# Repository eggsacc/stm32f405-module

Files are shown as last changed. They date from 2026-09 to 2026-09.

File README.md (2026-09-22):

<div align="center">

# STM32F405 Dev Module + BLDC hat





### MCU Dev
STM32F405RGT6 MCU dev module with commonly used peripherals broken out for easy access, and a dedicated CAN transceiver. Also includes 2 user programmable buttons and mini OLED display.

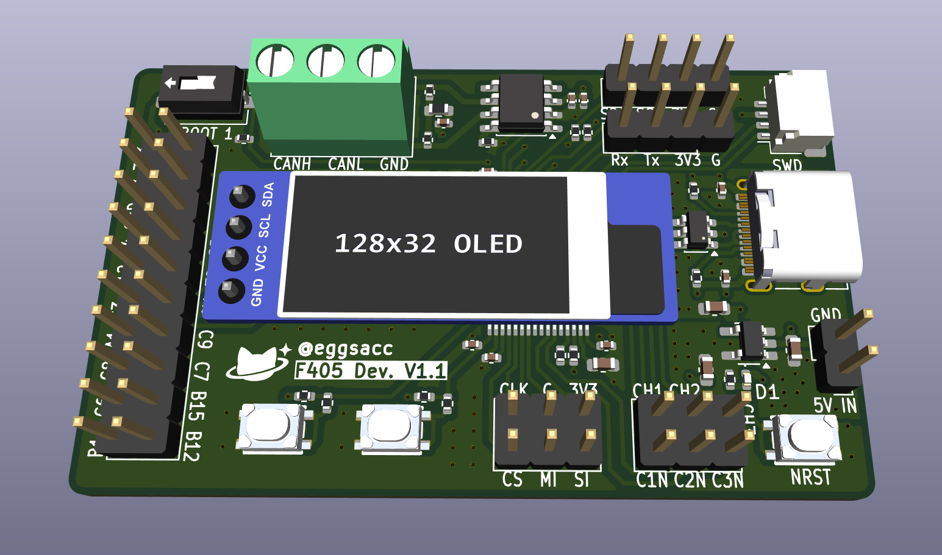
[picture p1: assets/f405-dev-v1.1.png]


### BLDC Dev
BLDC hat based on the DRV8316C integrated driver. 6-PWM mode, 5-35V input, 5A continuous and 3-phase low-side current sensing. Suitable for FOC algorithm developement and testing for low current gimbal motors.

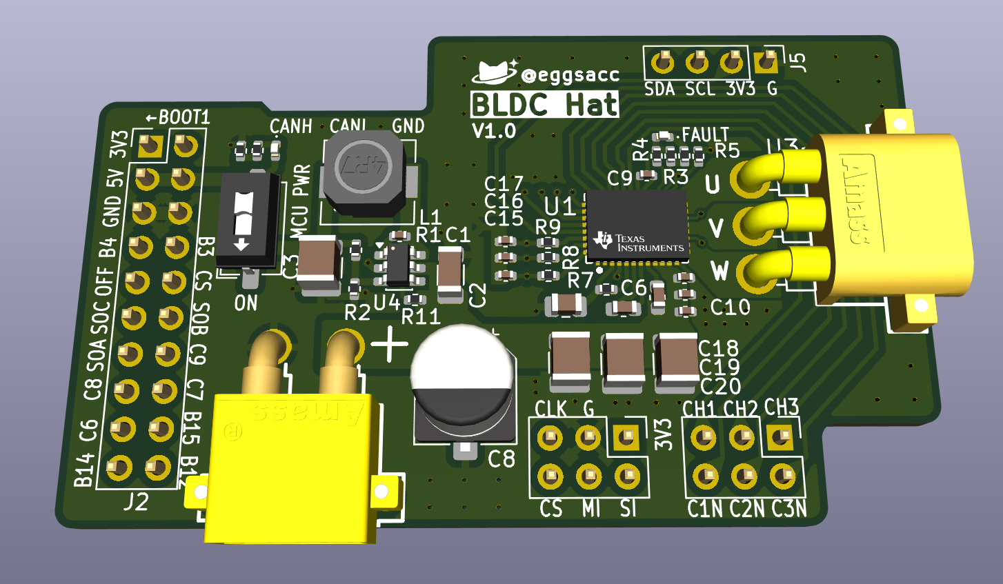
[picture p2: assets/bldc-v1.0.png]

</div>

---

## MCU Pinout

<div align="center">
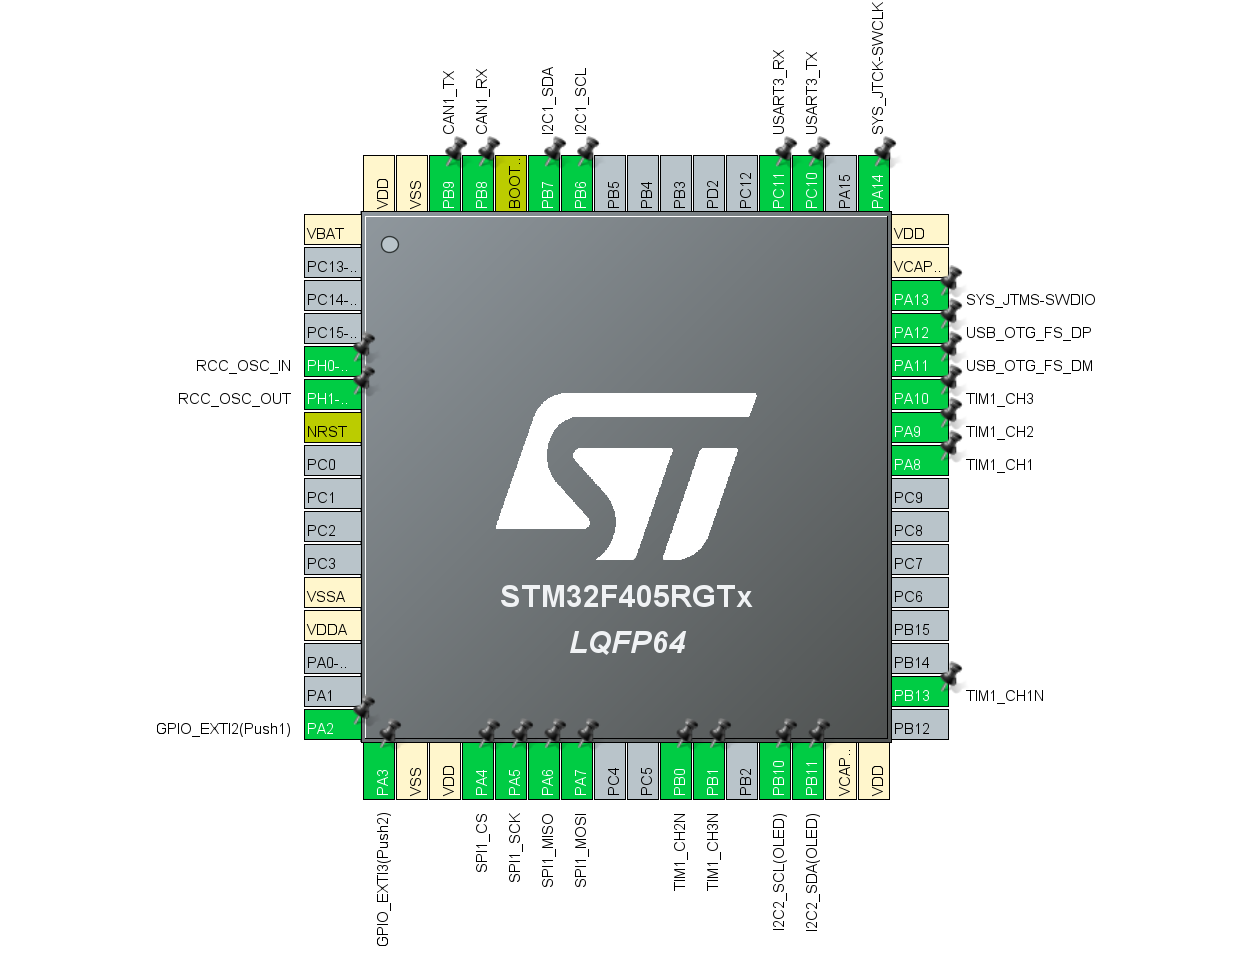
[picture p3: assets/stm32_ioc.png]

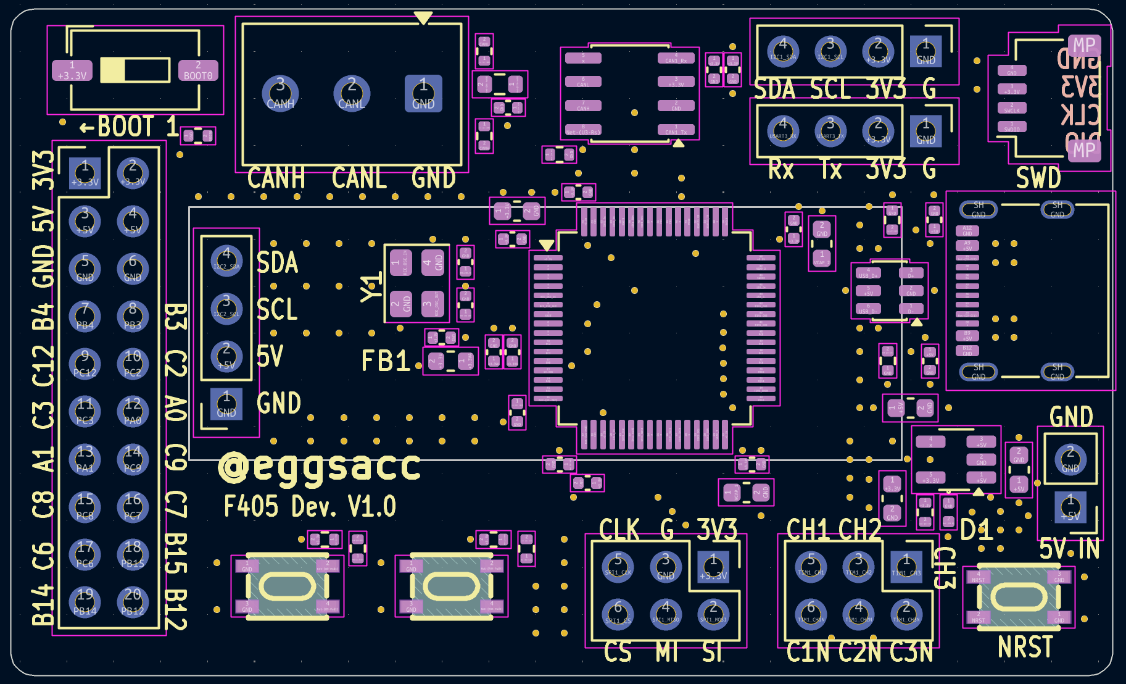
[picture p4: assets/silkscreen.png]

</div>

---

| Breakout / feature | Peripheral | Pin mapping |
|---|---|---|
| **UART header** | `USART3` | TX &rarr; `PC10`<br>RX &rarr; `PC11` |
| **SPI header** | `SPI1` | CS &rarr; `PA4`<br>SCK &rarr; `PA5`<br>MISO &rarr; `PA6`<br>MOSI &rarr; `PA7` |
| **I2C header** | `I2C1` | SCL &rarr; `PB6`<br>SDA &rarr; `PB7` |
| **CAN screw terminal** | `CAN1` (SN65HVD230) | TX &rarr; `PB9`<br>RX &rarr; `PB8` |
| **USB-C** | `USB_OTG_FS` | D&minus; &rarr; `PA11`<br>D+ &rarr; `PA12` |
| **SWD header** | `SYS` | SWDIO &rarr; `PA13`<br>SWCLK &rarr; `PA14` |
| **3-phase PWM header** | `TIM1` | <table><tbody><tr><td align="right">CH1 &rarr;</td><td><code>PA8</code></td><td align="right">&emsp;C1N &rarr;</td><td><code>PB13</code></td></tr><tr><td align="right">CH2 &rarr;</td><td><code>PA9</code></td><td align="right">&emsp;C2N &rarr;</td><td><code>PB0</code></td></tr><tr><td align="right">CH3 &rarr;</td><td><code>PA10</code></td><td align="right">&emsp;C3N &rarr;</td><td><code>PB1</code></td></tr></tbody></table> |
| **OLED** (on-board) | `I2C2` | SCL &rarr; `PB10`<br>SDA &rarr; `PB11` |
| **Utility buttons** (on-board) | `GPIO` / `EXTI` | L button &rarr; `PA2`<br>R button &rarr; `PA3` |
| **Crystal** (25MHz) | `RCC` HSE | OSC_IN &rarr; `PH0`<br>OSC_OUT &rarr; `PH1` |
| **GPIO header** (2&times;10) | free GPIO | <table><tbody><tr><td align="right">1 &rarr;</td><td><code>3.3V</code></td><td align="right">&emsp;2 &rarr;</td><td><code>3.3V</code></td></tr><tr><td align="right">3 &rarr;</td><td><code>5V</code></td><td align="right">&emsp;4 &rarr;</td><td><code>5V</code></td></tr><tr><td align="right">5 &rarr;</td><td><code>GND</code></td><td align="right">&emsp;6 &rarr;</td><td><code>GND</code></td></tr><tr><td align="right">7 &rarr;</td><td><code>PB4</code></td><td align="right">&emsp;8 &rarr;</td><td><code>PB3</code></td></tr><tr><td align="right">9 &rarr;</td><td><code>PC12</code></td><td align="right">&emsp;10 &rarr;</td><td><code>PC2</code></td></tr><tr><td align="right">11 &rarr;</td><td><code>PC3</code></td><td align="right">&emsp;12 &rarr;</td><td><code>PA0</code></td></tr><tr><td align="right">13 &rarr;</td><td><code>PA1</code></td><td align="right">&emsp;14 &rarr;</td><td><code>PC9</code></td></tr><tr><td align="right">15 &rarr;</td><td><code>PC8</code></td><td align="right">&emsp;16 &rarr;</td><td><code>PC7</code></td></tr><tr><td align="right">17 &rarr;</td><td><code>PC6</code></td><td align="right">&emsp;18 &rarr;</td><td><code>PB15</code></td></tr><tr><td align="right">19 &rarr;</td><td><code>PB14</code></td><td align="right">&emsp;20 &rarr;</td><td><code>PB12</code></td></tr></tbody></table> |

> Buttons are active-low to GND (3V3 pull-up).

---

## Power

>[!warning]Shared +5V rail
>5V rails are shared; do not connect USB and external power simultaneously!

- **USB-C**, 2-pin **`5V IN`** header, or `5V` on 2x10 breakout.
- AP2112K-3.3 LDO provides the 3.3 V rail (600 mA max).

---

## BLDC Hat hardware
<div align="center">
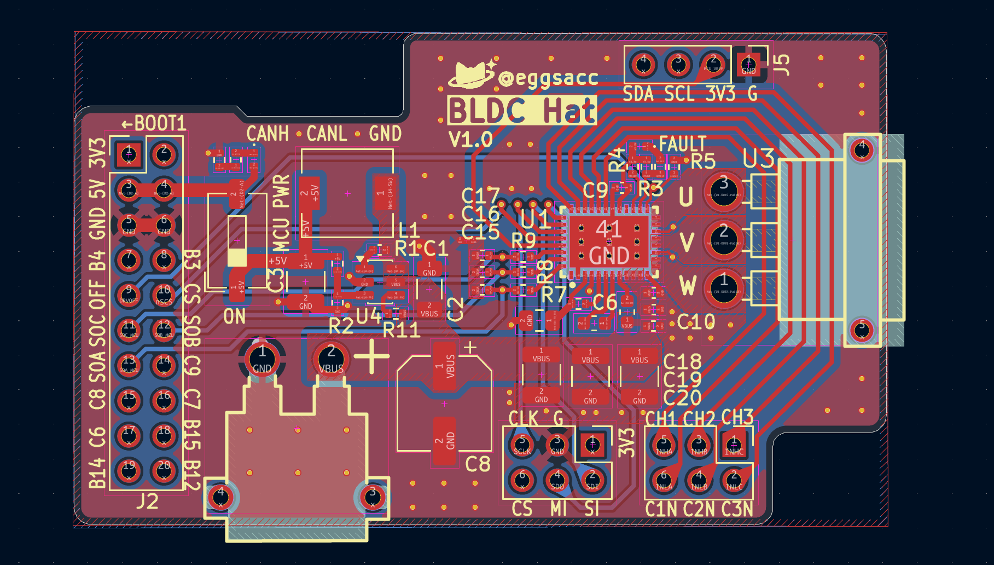
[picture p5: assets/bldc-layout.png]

</div>

---
<div align="center">
Designed by <b>@eggsacc</b> · F405 Dev. V1.1<br>
Updated 22/09/2026
</div>

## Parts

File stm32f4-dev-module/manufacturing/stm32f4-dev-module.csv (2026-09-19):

Reference | Qty | Value | Footprint | Purhased | Qty | Link
C1,C2,C3,C4,C5,C13,C16,C22,C23,C24 | 10 | 100n | Capacitor_SMD:C_0402_1005Metric | TRUE | 100 | 0402??????? 22pF33pF47pF100pF2.2nF4.7nF100nF1uF10uF-???
C6 | 1 | 10u | Capacitor_SMD:C_0603_1608Metric | TRUE | 100 | 0603??????? 22pF33pF47pF100pF2.2nF4.7nF100nF1uF10uF-???
C7,C21 | 2 | 10n | Capacitor_SMD:C_0402_1005Metric | TRUE | 100 | 0402??????? 22pF33pF47pF100pF2.2nF4.7nF100nF1uF10uF-???
C8,C9,C17 | 3 | 1u | Capacitor_SMD:C_0402_1005Metric | TRUE | 100 | 0402??????? 22pF33pF47pF100pF2.2nF4.7nF100nF1uF10uF-???
C10,C11 | 2 | 14p | Capacitor_SMD:C_0402_1005Metric | TRUE | 100 | 0402??????? 22pF33pF47pF100pF2.2nF4.7nF100nF1uF10uF-???
C14,C15 | 2 | 1u | Capacitor_SMD:C_0603_1608Metric | TRUE | 100 | 0603??????? 22pF33pF47pF100pF2.2nF4.7nF100nF1uF10uF-???
C18,C19 | 2 | 2u2 | Capacitor_SMD:C_0603_1608Metric | TRUE | 100 | 0603??????? 22pF33pF47pF100pF2.2nF4.7nF100nF1uF10uF-???
C20 | 1 | 4u7 | Capacitor_SMD:C_0603_1608Metric | TRUE | 100 | 0603??????? 22pF33pF47pF100pF2.2nF4.7nF100nF1uF10uF-???
D1 | 1 | GREEN | LED_SMD:LED_0402_1005Metric | TRUE | 10 | ??LED 0402 0603 0805 1206??????? ?????????-tmall.com??
FB1 | 1 | 120R | Inductor_SMD:L_0603_1608Metric | TRUE | 100 | 0603?????????30R60R100R120R150R220R300R600R1K2K2.5K-???
J1 | 1 | SW | Connector_JST:JST_SH_SM04B-SRSS-TB_1x04-1MP_P1.00mm_Horizontal | TRUE | 10 | ???SH1.0??JSTSH ???1.0mm????/??/???????-???
J3 | 1 | I2C1 | Connector_PinHeader_2.54mm:PinHeader_1x04_P2.54mm_Vertical | TRUE | 0
J4 | 1 | SPI1 | Connector_PinHeader_2.54mm:PinHeader_2x03_P2.54mm_Vertical | TRUE | 0 | ?/??? ??2.54MM 1*2p/3p/4p/8P/16p/20p?? LCD1602/12864-tmall.com??
J5 | 1 | 5V_IN | Connector_PinHeader_2.54mm:PinHeader_1x02_P2.54mm_Vertical | TRUE | 0
J6 | 1 | OLED | addons:OLED header | TRUE | 0
J7 | 1 | USB_C_Receptacle_USB2.0_16P | Connector_USB:USB_C_Receptacle_G-Switch_GT-USB-7010ASV | TRUE | 0 | USB Type-C 16P?????????????????USB???-???
J8 | 1 | USART3 | Connector_PinHeader_2.54mm:PinHeader_1x04_P2.54mm_Vertical | TRUE | 0
J9 | 1 | PWM | Connector_PinHeader_2.54mm:PinHeader_2x03_P2.54mm_Vertical | TRUE | 0
J10 | 1 | Screw_Terminal_01x03 | TerminalBlock_Phoenix:TerminalBlock_Phoenix_MKDS-1-3-3.81_1x03_P3.81mm_Horizontal | TRUE | 0 | KF128/126????2P???2.54/3.81/5.08MM??5.0?????3P-tmall.com??
J11 | 1 | Conn_02x10_Odd_Even | Connector_PinHeader_2.54mm:PinHeader_2x10_P2.54mm_Vertical | TRUE | 0
R1,R3,R10,R12 | 4 | 10k | Resistor_SMD:R_0402_1005Metric | TRUE | 0 | 0402?????? ??1% 10R1K1.2K2.2K3.3K4.7K5.1K10K100K1M?-???
R2 | 1 | 330 | Resistor_SMD:R_0402_1005Metric | TRUE | 0 | 0402?????? ??1% 10R1K1.2K2.2K3.3K4.7K5.1K10K100K1M?-???
R4,R5 | 2 | 60 | Resistor_SMD:R_0402_1005Metric | TRUE | 0 | 0402?????? ??1% 10R1K1.2K2.2K3.3K4.7K5.1K10K100K1M?-???
R6 | 1 | 0 | Resistor_SMD:R_0603_1608Metric | TRUE | 0 | 0402 0603 0805 1206????1%5% 1R10R100R1K 4.7K10K 47K 100K-???
R7,R8 | 2 | 5k1 | Resistor_SMD:R_0402_1005Metric | TRUE | 0 | 0402?????? ??1% 10R1K1.2K2.2K3.3K4.7K5.1K10K100K1M?-???
R9,R11 | 2 | 100 | Resistor_SMD:R_0402_1005Metric | TRUE | 0 | 0402?????? ??1% 10R1K1.2K2.2K3.3K4.7K5.1K10K100K1M?-???
SW1 | 1 | SW_SPST | Button_Switch_SMD:SW_DIP_SPSTx01_Slide_6.7x4.1mm_W6.73mm_P2.54mm_LowProfile_JPin | TRUE | 10 | ??????/??1/2/3/4/5/6/7/8/9/10/12p??1.27/2.54mm??-???
SW5,SW6 | 2 | BTN_UTIL | addons:SW-SMD_4P-L4.2-W3.4-P2.15-LS5.2 | TRUE | 0 | ????4???2??????????????????????-tmall.com??
SW7 | 1 | BTN | addons:SW-SMD_4P-L4.2-W3.4-P2.15-LS5.2 | TRUE | 40 | ????4???2??????????????????????-tmall.com??
U1 | 1 | STM32F405RGT6 | Package_QFP:LQFP-64_10x10mm_P0.5mm | TRUE | 2 | ???? STM32F405RGT6 STM32F405VGT6 405ZGT6 405OEY6TR VGT7-tmall.com??
U2 | 1 | USBLC6-2SC6 | Package_TO_SOT_SMD:SOT-23-6 | TRUE | 20 | USBLC6-2SC6 USB2.0??ESD????? ???? ??UL26 SOT-23-tmall.com??
U3 | 1 | SN65HVD230 | Package_SO:SOIC-8_3.9x4.9mm_P1.27mm | TRUE | 5 | ???? ?? SN65HVD230DR SOP-8 CAN????? ??-???
U4 | 1 | AP2112K-3.3 | Package_TO_SOT_SMD:SOT-23-5_HandSoldering | TRUE | 10 | AP2112K-3.3TRG1 1.2V 1.8V 2.5V ??G3M LDO????? SOT23-5-???
Y1 | 1 | 25MHz | Crystal:Crystal_SMD_3225-4Pin_3.2x2.5mm | TRUE | 10 | 3225_4P???????? 8/12/13.56/16/20/24/25/26/32/40MHz-???
 |  |  | Request from seller values
 | ??
 | 1 | 100nF, 16V, X7R | 0402
 | 2 | 10nF, 50V, X7R | 0402
 | 3 | 1uF, 25V, X5R, 10% | 0402
 | 4 | 13pF, 50V, C0G | 0402
 | 5 | 1uF, 16V, X7R, 10% | 0603
 | 6 | 2.2uF, 16V, X7R, 10% | 0603
 | 7 | 4.7uF, 16V, X5R, 10% | 0603
 | 8 | 10uF, 10V, X5R, 10% | 0603
 | ??
 | 1 | 10k | 0402
 | 2 | 330 | 0402
 | 3 | 60 | 0402
 | 4 | 5.1K | 0402
 | 5 | 100 | 0403
 | 6 | 0 | 0603

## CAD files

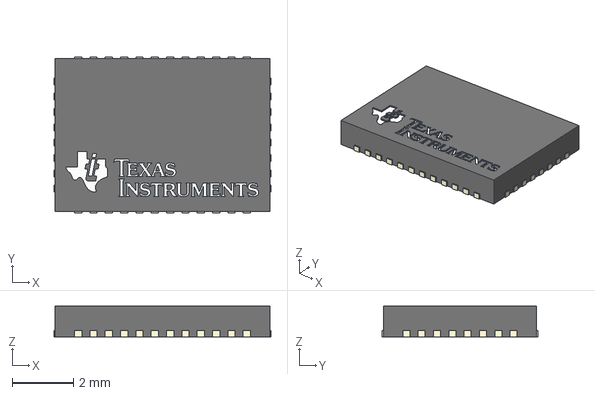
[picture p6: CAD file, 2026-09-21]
bldc-hat/3d-models/VQFN40p-7x5-TI.step
7.08 x 5.09 x 1.00 mm

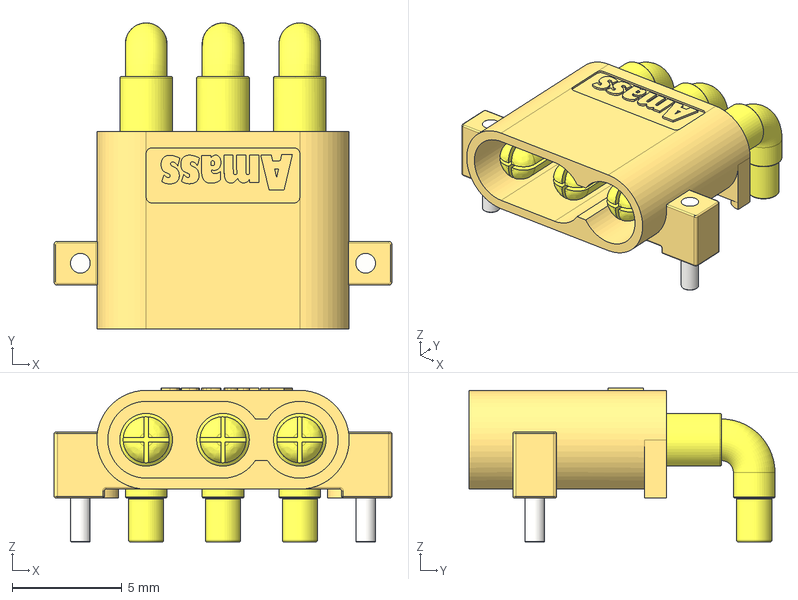
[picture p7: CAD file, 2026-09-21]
bldc-hat/3d-models/MR30PW-M v2.step
15.4 x 13.9 x 7.00 mm
PCB Pins
Pin 2 x 3

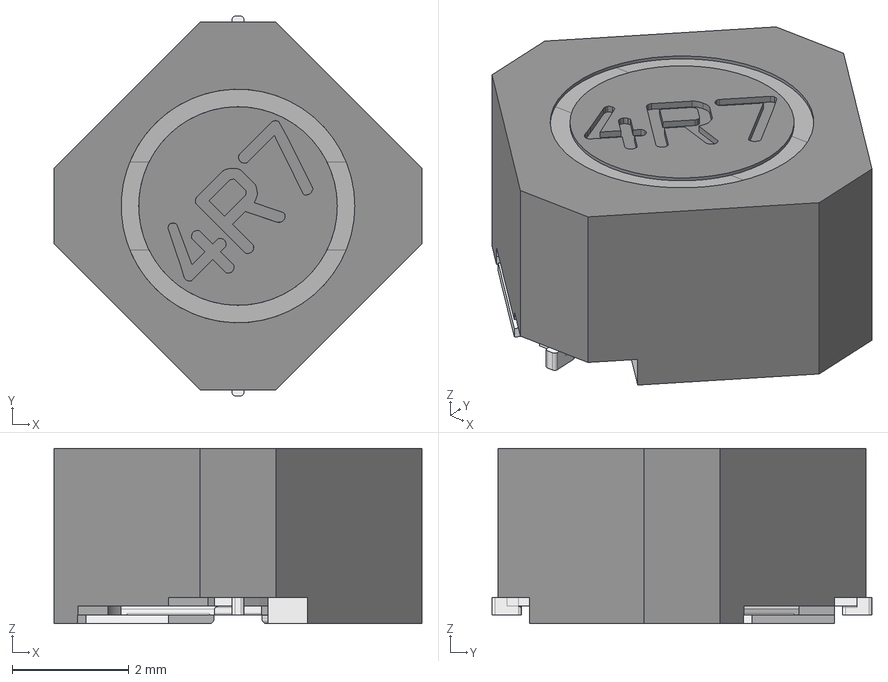
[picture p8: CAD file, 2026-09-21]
bldc-hat/3d-models/Inductor_63.step
6.30 x 6.50 x 3.00 mm
Protection
Inner_Pins
Inductor_Core
Pins
Inductor_Case

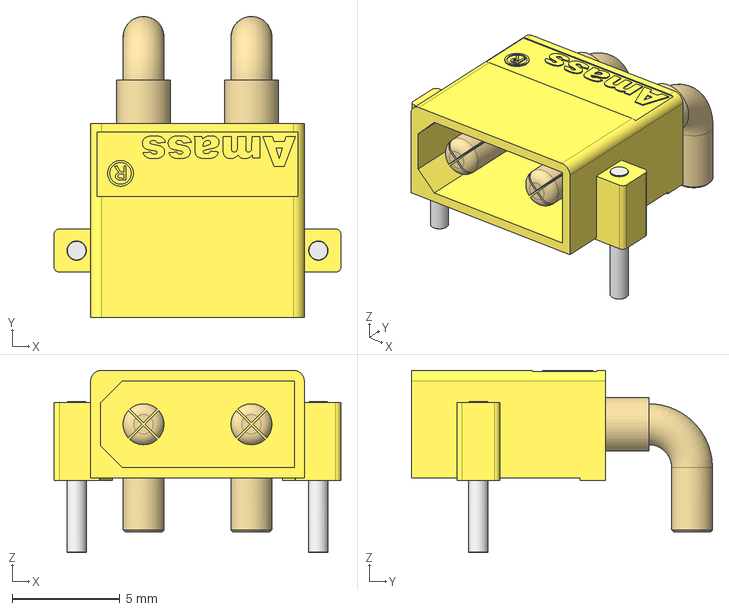
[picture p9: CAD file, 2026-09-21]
bldc-hat/3d-models/Amass_XT30PW-M_pcb solder.stp
13.3 x 13.9 x 8.45 mm

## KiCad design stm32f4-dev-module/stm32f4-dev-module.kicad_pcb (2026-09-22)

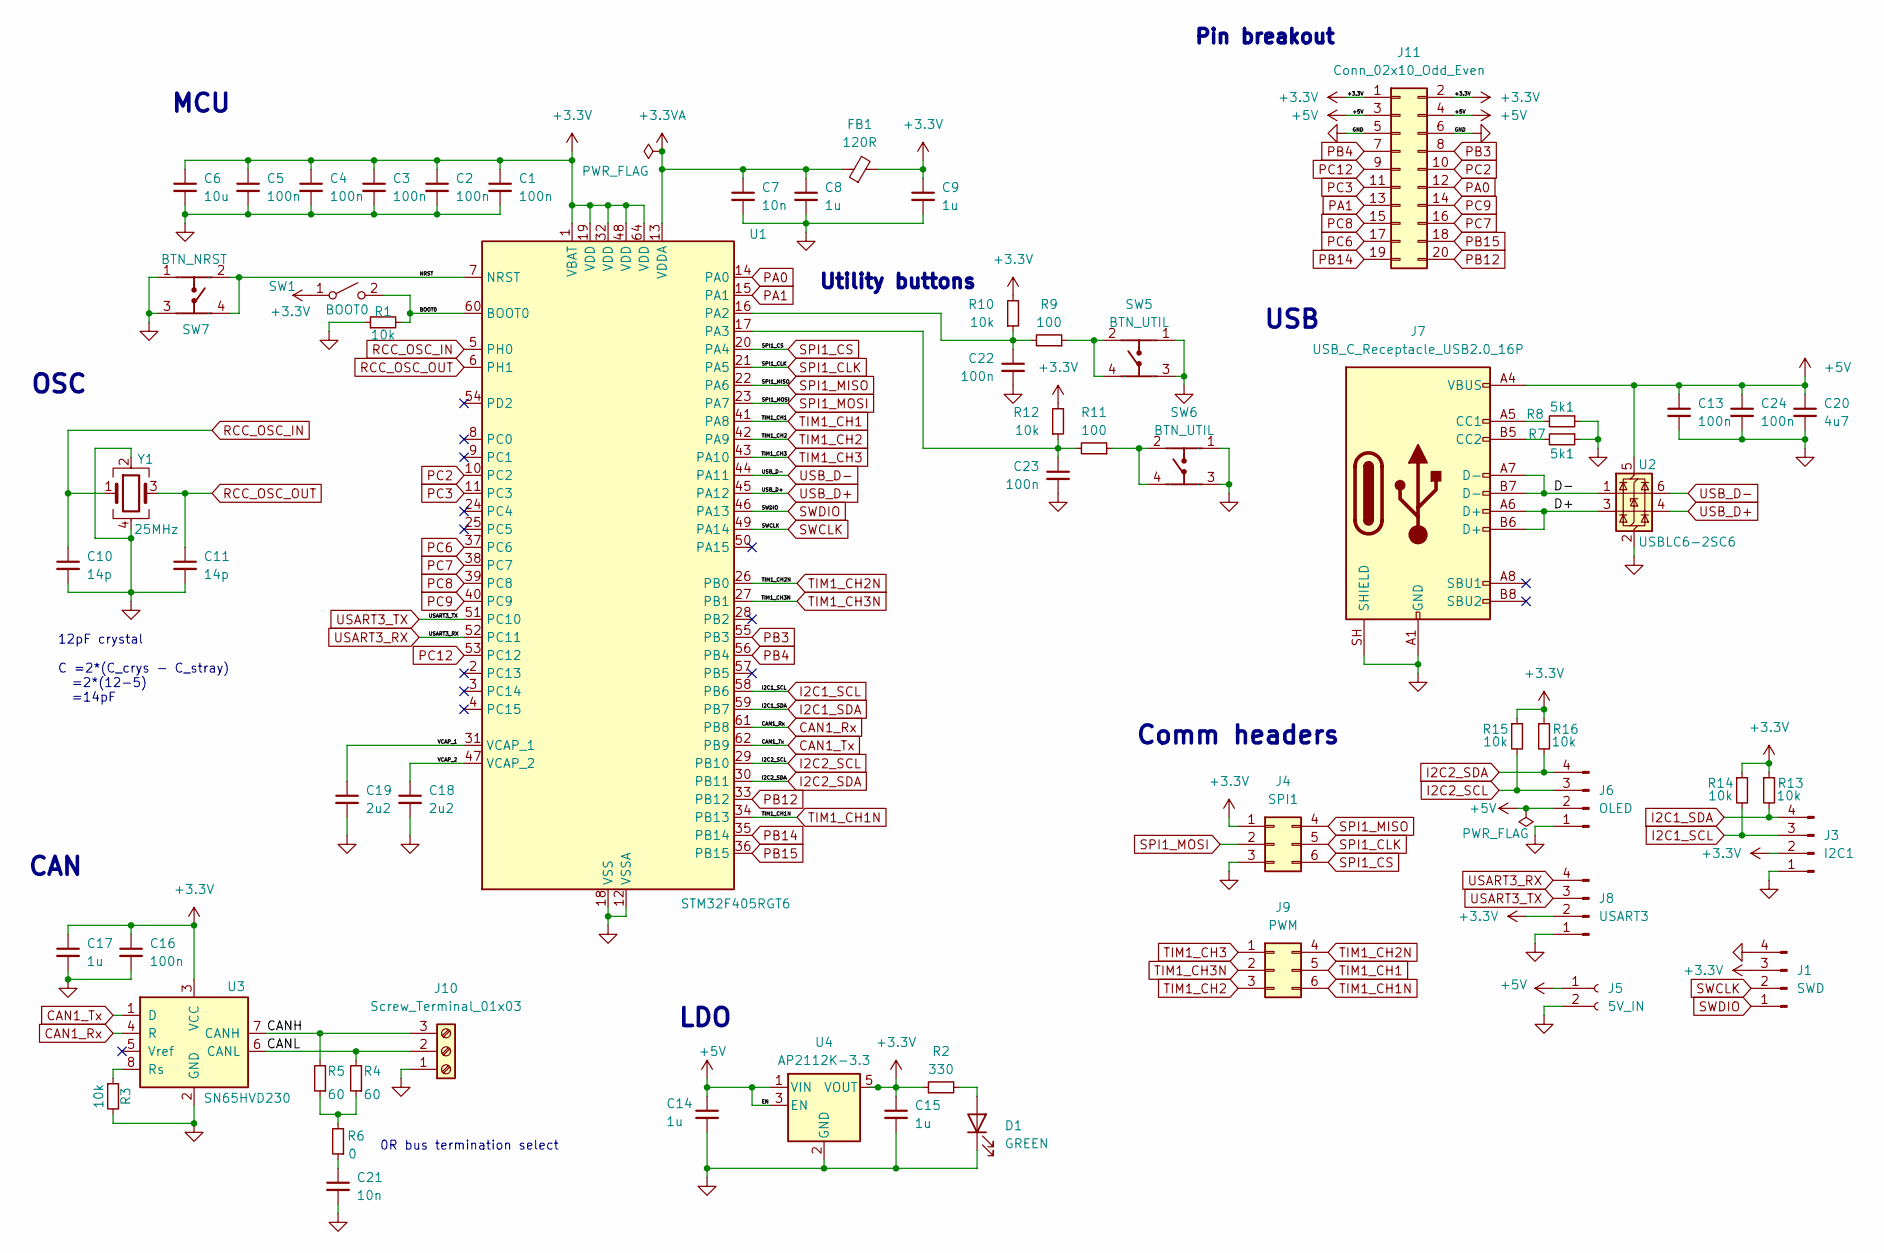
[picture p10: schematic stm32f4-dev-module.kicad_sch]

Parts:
C1, C2, C3, C4, C5, C13, C16, C22, C23, C24: 100n; C_0402_1005Metric
C6: 10u; C_0603_1608Metric
C7, C21: 10n; C_0402_1005Metric
C8, C9, C17: 1u; C_0402_1005Metric
C10, C11: 14p; C_0402_1005Metric
C14, C15: 1u; C_0603_1608Metric
C18, C19: 2u2; C_0603_1608Metric
C20: 4u7; C_0603_1608Metric
D1: GREEN; LED_0402_1005Metric
FB1: 120R; L_0603_1608Metric
J1: SWD; JST_SH_SM04B-SRSS-TB_1x04-1MP_P1.00mm_Horizontal
J3: I2C1; PinHeader_1x04_P2.54mm_Vertical
J4: SPI1; PinHeader_2x03_P2.54mm_Vertical
J5: 5V_IN; PinHeader_1x02_P2.54mm_Vertical
J6: OLED; OLED header
J7: USB_C_Receptacle_USB2.0_16P; USB_C_Receptacle_G-Switch_GT-USB-7010ASV
J8: USART3; PinHeader_1x04_P2.54mm_Vertical
J9: PWM; PinHeader_2x03_P2.54mm_Vertical
J10: Screw_Terminal_01x03; TerminalBlock_Phoenix_MKDS-1-3-3.81_1x03_P3.81mm_Horizontal
J11: Conn_02x10_Odd_Even; PinHeader_2x10_P2.54mm_Vertical
R1, R3, R10, R12, R13, R14, R15, R16: 10k; R_0402_1005Metric
R2: 330; R_0402_1005Metric
R4, R5: 60; R_0402_1005Metric
R6: 0; R_0603_1608Metric
R7, R8: 5k1; R_0402_1005Metric
R9, R11: 100; R_0402_1005Metric
SW1: BOOT0; SW_DIP_SPSTx01_Slide_6.7x4.1mm_W6.73mm_P2.54mm_LowProfile_J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
SW5, SW6: BTN_UTIL; SW-SMD_4P-L4.2-W3.4-P2.15-LS5.2; Manufacturer Part HX 3x4x2.5-PA-4N push button switch
SW7: BTN_NRST; SW-SMD_4P-L4.2-W3.4-P2.15-LS5.2; Manufacturer Part HX 3x4x2.5-PA-4N push button switch
U1: STM32F405RGT6; LQFP-64_10x10mm_P0.5mm
U2: USBLC6-2SC6; SOT-23-6
U3: SN65HVD230; SOIC-8_3.9x4.9mm_P1.27mm
U4: AP2112K-3.3; SOT-23-5_HandSoldering
Y1: 25MHz; Crystal_SMD_3225-4Pin_3.2x2.5mm

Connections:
+3.3V: C1.1, C2.1, C3.1, C4.1, C5.1, C6.1, C9.1, C15.1, C16.1, C17.1, FB1.2, J1.3, J3.2, J4.1, J8.2, J11.1, J11.2, R2.1, R10.2, R12.2, R13.1, R14.1, R15.1, R16.1, SW1.1 (A), U1.1 (VBAT), U1.19 (VDD), U1.32 (VDD), U1.48 (VDD), U1.64 (VDD), U3.3 (VCC), U4.5 (VOUT)
+3.3VA: C7.1, C8.1, FB1.1, U1.13 (VDDA)
+5V: C13.1, C14.1, C20.1, C24.1, J5.1, J6.2, J7.A4 (VBUS), J7.A9 (VBUS), J7.B4 (VBUS), J7.B9 (VBUS), J11.3, J11.4, U2.5 (VBUS), U4.1 (VIN), U4.3 (EN)
/BOOT0: R1.2, SW1.2 (B), U1.60 (BOOT0)
/CANH: J10.3, R5.2, U3.7 (CANH)
/CANL: J10.2, R4.2, U3.6 (CANL)
/D+: J7.A6 (D+), J7.B6 (D+), U2.3 (I/O2)
/D-: J7.A7 (D-), J7.B7 (D-), U2.1 (I/O1)
/NRST: SW7.2, SW7.4, U1.7 (NRST)
/VCAP_1: C19.1, U1.31 (VCAP_1)
/VCAP_2: C18.1, U1.47 (VCAP_2)
CAN1_Rx: U1.61 (PB8), U3.4 (R)
CAN1_Tx: U1.62 (PB9), U3.1 (D)
GND: C1.2, C2.2, C3.2, C4.2, C5.2, C6.2, C7.2, C8.2, C9.2, C10.2, C11.2, C13.2, C14.2, C15.2, C16.2, C17.2, C18.2, C19.2, C20.2, C21.2, C22.2, C23.2, C24.2, D1.1 (K), J1.4, J3.1, J4.3, J5.2, J6.1, J7.A1 (GND), J7.A12 (GND), J7.B1 (GND), J7.B12 (GND), J7.SH (SHIELD), J8.1, J10.1, J11.5, J11.6, R1.1, R3.2, R7.1, R8.1, SW5.1, SW5.3, SW6.1, SW6.3, SW7.1, SW7.3, U1.12 (VSSA), U1.18 (VSS), U1.63 (VSS), U2.2 (GND), U3.2 (GND), U4.2 (GND), Y1.2, Y1.4
I2C1_SCL: J3.3, R14.2, U1.58 (PB6)
I2C1_SDA: J3.4, R13.2, U1.59 (PB7)
I2C2_SCL: J6.3, R15.2, U1.29 (PB10)
I2C2_SDA: J6.4, R16.2, U1.30 (PB11)
unnamed: C21.1, R6.1
unnamed: D1.2 (A), R2.2
unnamed: J7.A5 (CC1), R8.2
unnamed: J7.B5 (CC2), R7.2
unnamed: R4.1, R5.1, R6.2
unnamed: R9.1, SW5.2, SW5.4
unnamed: R11.1, SW6.2, SW6.4
unnamed: C22.1, R9.2, R10.1, U1.16 (PA2)
unnamed: C23.1, R11.2, R12.1, U1.17 (PA3)
unnamed: R3.1, U3.8 (Rs)
PA0: J11.12, U1.14 (PA0)
PA1: J11.13, U1.15 (PA1)
PB3: J11.8, U1.55 (PB3)
PB4: J11.7, U1.56 (PB4)
PB12: J11.20, U1.33 (PB12)
PB14: J11.19, U1.35 (PB14)
PB15: J11.18, U1.36 (PB15)
PC2: J11.10, U1.10 (PC2)
PC3: J11.11, U1.11 (PC3)
PC6: J11.17, U1.37 (PC6)
PC7: J11.16, U1.38 (PC7)
PC8: J11.15, U1.39 (PC8)
PC9: J11.14, U1.40 (PC9)
PC12: J11.9, U1.53 (PC12)
RCC_OSC_IN: C10.1, U1.5 (PH0), Y1.1
RCC_OSC_OUT: C11.1, U1.6 (PH1), Y1.3
SPI1_CLK: J4.5, U1.21 (PA5)
SPI1_CS: J4.6, U1.20 (PA4)
SPI1_MISO: J4.4, U1.22 (PA6)
SPI1_MOSI: J4.2, U1.23 (PA7)
SWCLK: J1.2, U1.49 (PA14)
SWDIO: J1.1, U1.46 (PA13)
TIM1_CH1: J9.5, U1.41 (PA8)
TIM1_CH1N: J9.6, U1.34 (PB13)
TIM1_CH2: J9.3, U1.42 (PA9)
TIM1_CH2N: J9.4, U1.26 (PB0)
TIM1_CH3: J9.1, U1.43 (PA10)
TIM1_CH3N: J9.2, U1.27 (PB1)
USART3_RX: J8.4, U1.52 (PC11)
USART3_TX: J8.3, U1.51 (PC10)
USB_D+: U1.45 (PA12), U2.4 (I/O2)
USB_D-: U1.44 (PA11), U2.6 (I/O1)

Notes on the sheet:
MCU
Pin breakout
Comm headers
CAN
12pF crystal C =2*(C_crys - C_stray) =2*(12-5) =14pF
USB
Utility buttons
LDO
OSC
0R bus termination select

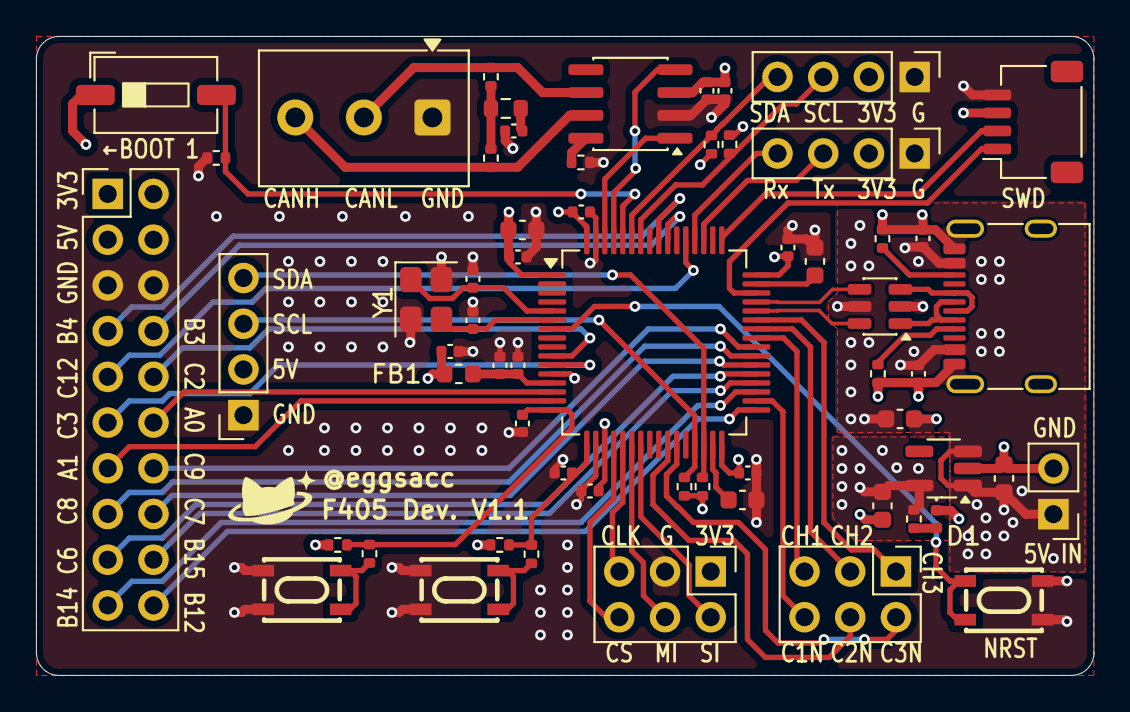
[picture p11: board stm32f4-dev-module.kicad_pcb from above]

Board: 4 copper layers, 58.8 x 35.5 mm, 60 parts (0 on the bottom side), 60 nets.

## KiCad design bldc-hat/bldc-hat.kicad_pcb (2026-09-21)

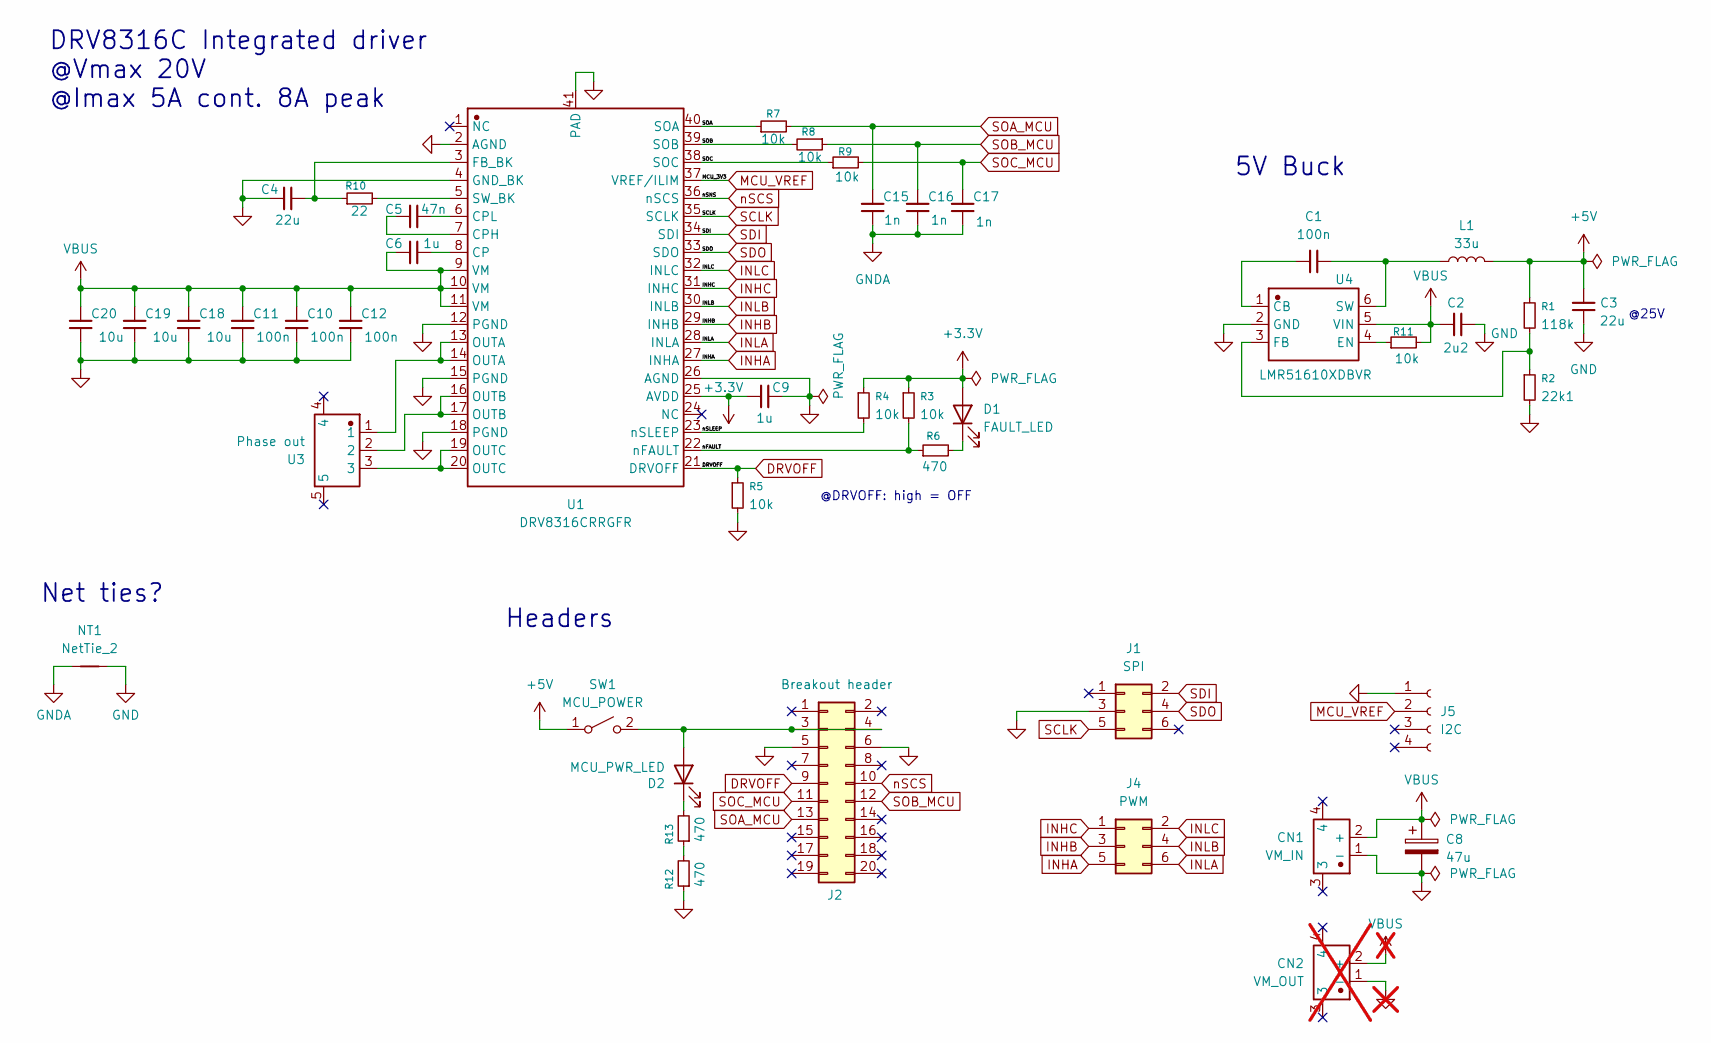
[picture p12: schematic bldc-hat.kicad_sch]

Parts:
C1, C10, C11, C12: 100n; C_0402_1005Metric
C2: 2u2; C_1206_3216Metric
C3: 22u; C_1210_3225Metric
C4: 22u; C_0805_2012Metric
C5: 47n; C_0603_1608Metric
C6: 1u; C_0603_1608Metric
C8: 47u; CP_Elec_6.3x7.7
C9: 1u; C_0402_1005Metric
C15, C16, C17: 1n; C_0402_1005Metric
C18, C19, C20: 10u; C_1210_3225Metric
CN1: VM_IN; CONN-TH_XT30PW-M; Manufacturer Part XT30PW-M
CN2: VM_OUT; CONN-TH_XT30PW-M; Manufacturer Part XT30PW-M; not fitted
D1: FAULT_LED; LED_0402_1005Metric
D2: MCU_PWR_LED; LED_0402_1005Metric
J1: SPI; PinHeader_2x03_P2.54mm_Vertical
J2: Breakout header; PinHeader_2x10_P2.54mm_Vertical
J4: PWM; PinHeader_2x03_P2.54mm_Vertical
J5: I2C; PinHeader_1x04_P2.54mm_Vertical
L1: 33u; L_6.3x6.3_H3
NT1: NetTie_2; NetTie-2_SMD_Pad0.5mm
R1: 118k; R_0402_1005Metric
R2: 22k1; R_0402_1005Metric
R3, R4, R5, R7, R8, R9, R11: 10k; R_0402_1005Metric
R6, R12, R13: 470; R_0402_1005Metric
R10: 22; R_0402_1005Metric
SW1: MCU_POWER; SW_DIP_SPSTx01_Slide_6.7x4.1mm_W6.73mm_P2.54mm_LowProfile_J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
U1: DRV8316CRRGFR; DRV8316CR; Manufacturer Part DRV8316CRRGFR
U3: Phase out; CONN-TH_MR30PW-M30-G-Y; Manufacturer Part MR30PW-M30.G.Y
U4: LMR51610XDBVR; SOT-23-6; Manufacturer Part LMR51610XDBVR

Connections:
+3.3V: C9.1, D1.2 (A), R3.1, R4.1, U1.25 (AVDD)
+5V: C3.1, L1.2, R1.1, SW1.1 (A)
/SOA: R7.1, U1.40 (SOA)
/SOB: R8.2, U1.39 (SOB)
/SOC: R9.1, U1.38 (SOC)
/nFAULT: R3.2, R6.1, U1.22 (nFAULT)
/nSLEEP: R4.2, U1.23 (nSLEEP)
DRVOFF: J2.9, R5.1, U1.21 (DRVOFF)
GND: C2.1, C3.2, C4.2, C8.2, C9.2, C10.2, C11.2, C12.2, C18.2, C19.2, C20.2, CN1.1 (-), CN2.1 (-), J1.3, J2.5, J2.6, J5.1, NT1.2, R2.2, R5.2, R12.1, U1.2 (AGND), U1.4 (GND_BK), U1.12 (PGND), U1.15 (PGND), U1.18 (PGND), U1.26 (AGND), U1.41 (PAD), U4.2 (GND); also elsewhere on the board
GNDA: C15.2, C16.2, C17.2, NT1.1; also elsewhere on the board
INHA: J4.5, U1.27 (INHA)
INHB: J4.3, U1.29 (INHB)
INHC: J4.1, U1.31 (INHC)
INLA: J4.6, U1.28 (INLA)
INLB: J4.4, U1.30 (INLB)
INLC: J4.2, U1.32 (INLC)
MCU_VREF: J5.2, U1.37 (VREF/ILIM)
unnamed: D1.1 (K), R6.2
unnamed: D2.2 (A), J2.3, J2.4, SW1.2 (B)
unnamed: D2.1 (K), R13.2
unnamed: R12.2, R13.1
unnamed: C6.2, U1.8 (CP)
unnamed: C5.1, U1.7 (CPH)
unnamed: C5.2, U1.6 (CPL)
unnamed: C4.1, R10.1, U1.3 (FB_BK)
unnamed: U1.13 (OUTA), U1.14 (OUTA), U3.1
unnamed: U1.16 (OUTB), U1.17 (OUTB), U3.2
unnamed: U1.19 (OUTC), U1.20 (OUTC), U3.3
unnamed: R10.2, U1.5 (SW_BK)
unnamed: C1.1, U4.1 (CB)
unnamed: R11.1, U4.4 (EN)
unnamed: R1.2, R2.1, U4.3 (FB)
unnamed: C1.2, L1.1, U4.6 (SW)
SCLK: J1.5, U1.35 (SCLK)
SDI: J1.2, U1.34 (SDI)
SDO: J1.4, U1.33 (SDO)
SOA_MCU: C15.1, J2.13, R7.2
SOB_MCU: C16.1, J2.12, R8.1
SOC_MCU: C17.1, J2.11, R9.2
VBUS: C2.2, C6.1, C8.1, C10.1, C11.1, C12.1, C18.1, C19.1, C20.1, CN1.2 (+), CN2.2 (+), R11.2, U1.9 (VM), U1.10 (VM), U1.11 (VM), U4.5 (VIN)
nSCS: J2.10, U1.36 (nSCS)

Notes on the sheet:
DRV8316C Integrated driver @Vmax 20V @Imax 5A cont. 8A peak
@DRVOFF: high = OFF
Net ties?
5V Buck
Headers
@25V

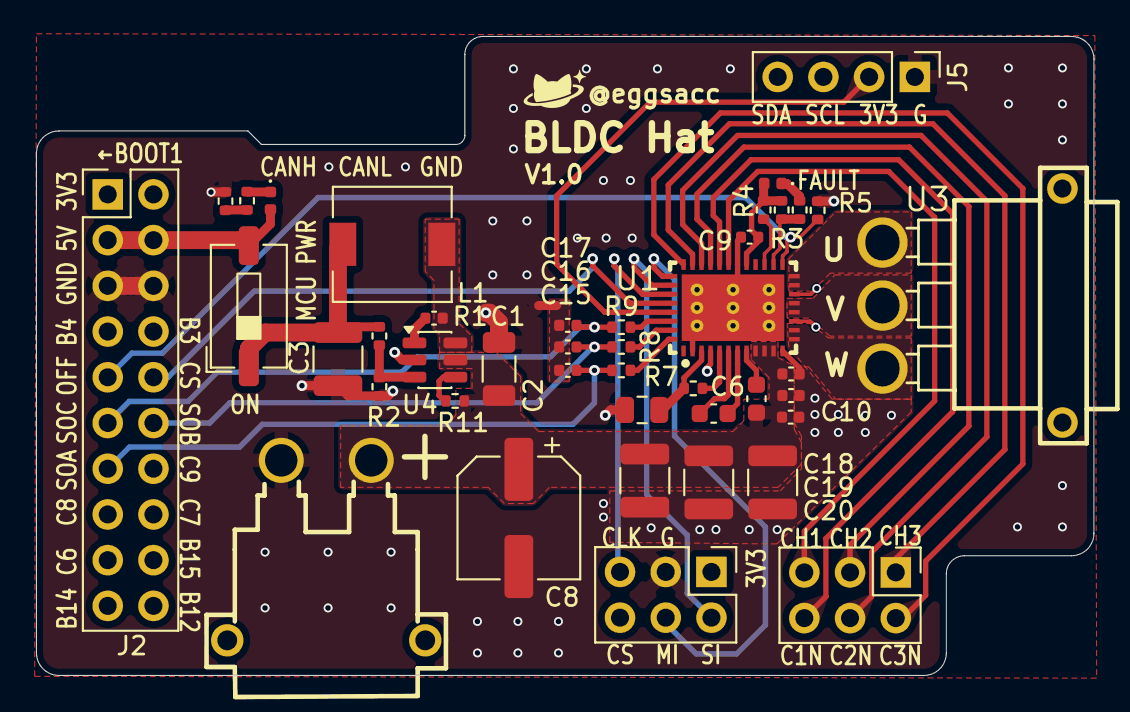
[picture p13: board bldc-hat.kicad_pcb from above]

Board: 4 copper layers, 58.8 x 35.5 mm, 43 parts (0 on the bottom side), 41 nets.

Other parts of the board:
NT3: NetTie_2; NetTie-2_SMD_Pad0.5mm

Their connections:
GND: NT3.2; also elsewhere on the board
GNDA: NT3.1; also elsewhere on the board

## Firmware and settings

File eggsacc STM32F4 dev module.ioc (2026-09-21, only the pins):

Mcu.UserName=STM32F405RGTx
PA0-WKUP.Signal=ADCx_IN0
PA1.Signal=ADCx_IN1
PA10.Signal=S_TIM1_CH3
PA11.Signal=USB_OTG_FS_DM
PA12.Signal=USB_OTG_FS_DP
PA13.Signal=SYS_JTMS-SWDIO
PA14.Signal=SYS_JTCK-SWCLK
PA2.GPIO_Label=GPIO_EXTI2(Push1)
PA2.Signal=GPXTI2
PA3.GPIO_Label=GPIO_EXTI3(Push2)
PA3.Signal=GPXTI3
PA4.GPIO_Label=SPI1_CS
PA4.Signal=GPIO_Output
PA5.Signal=SPI1_SCK
PA6.Signal=SPI1_MISO
PA7.Signal=SPI1_MOSI
PA8.Signal=S_TIM1_CH1
PA9.Signal=S_TIM1_CH2
PB0.Signal=TIM1_CH2N
PB1.Signal=TIM1_CH3N
PB10.GPIO_Label=I2C2_SCL(OLED)
PB10.Signal=I2C2_SCL
PB11.GPIO_Label=I2C2_SDA(OLED)
PB11.Signal=I2C2_SDA
PB13.Signal=TIM1_CH1N
PB6.Signal=I2C1_SCL
PB7.Signal=I2C1_SDA
PB8.Signal=CAN1_RX
PB9.Signal=CAN1_TX
PC10.Signal=USART3_TX
PC11.Signal=USART3_RX
PC3.Signal=ADCx_IN13
PH0-OSC_IN.Signal=RCC_OSC_IN
PH1-OSC_OUT.Signal=RCC_OSC_OUT

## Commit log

2026-09-19 Release V1.0
    [stm32f4-dev-module-B_Cu.gbr, stm32f4-dev-module-B_Mask.gbr, stm32f4-dev-module-B_Paste.gbr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]
2026-09-21 added BLDC hat project
    [Amass_XT30PW-M_pcb solder.stp, Inductor_63.step, MR30PW-M v2.step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]
2026-09-22 Dev. module V1.1: added pull up resistors to i2c lines.
    [stm32f4-dev-module.kicad_pcb, stm32f4-dev-module.kicad_sch]
